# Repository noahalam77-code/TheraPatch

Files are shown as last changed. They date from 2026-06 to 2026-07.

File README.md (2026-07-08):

# TheraPatch

## Repository file structure
- BOM: JCLPCB BOM & regular BOM
- CADfiles: STEP files, STL files, and assembly notes
- PCB: PCB files, Gerber files, schematic images, and PCB images
- Firmware: Code & flashing instructions

## What it is
TheraPatch is a handheld therapeutic device designed to help mitigate the effects of injuries such as bruises, sprains, minor cuts, and more. By using a reverse-polarity system via an H-bridge, TheraPatch can heat the affected area (dilating blood vessels) or cool it (constricting blood vessels), both of which have been shown to help with injury healing at certain temperatures (which TheraPatch can achieve). 

## Motivation
I created TheraPatch with the primary motivation of helping people with common sports/activty related injuries while maintaining an efficient device to do so. Most of the time, when you have a bruise or scrape, you'd rely on disposable ice packs or inefficient heating pads, which are wasteful and time-consuming for long-term use. TheraPatch offers an effective, infinitely reusable solution to this. Instead of freezing water for 3-4 hours or boiling a heatpack everytime you need to reuse it, all you do with TheraPatch is plug and play. It's effective for athletes and normal people.

## Use of TheraPatch
To use the TheraPatch, first ensure your battery/wall adapter is plugged in. Then locate the 4 buttons on the top of the device; these buttons will allow you to set your desired parameters by moving through the menus: mode (hot/cold), set temp, and set time. After your desired settings are set, click the start button to initiate your therapy session, and place the side with the Peltier facing out against the affected area

## How it works
The TheraPatch looks like a simple black-and-white hot-cold block, but its guts are far more advanced. In electronics, generating heat is relatively simple. Electrons bump into each other rapidly in the wire, vibrating and thus creating the heat we feel. This is the easy part; cooling is the real engineering challenge. To cool it, I used a Peltier module, which transfers heat from one side to the other. Now, this needs to be driven by a heatsink and a fan to effectively cool. To achieve heating and cooling on the same side, I used an H bridge. The H-bridge module reverses the polarity in a Peltier module, meaning that when one side is positive and the other is negative, it cools; vice versa. All of this is controlled by a custom 4-layer PCB I designed in KiCad, with an ATmega328P as my microcontroller. The firmware reads a thermistor pressed against the Peltier plate and uses a bang-bang controller to turn the Peltier on/off to reach the desired temperature. This is all run by a rechargeable 12V battery, which charges via USB-C or a 12V wall adapter. These components are combined in a logical order in a CAD-designed box with a hole for all the input plugs and vent fans for air circulation.

Here are images of my project

## CAD with the PCB:

Screenshot 2026-07-04 at 1 53 12 PM

Screenshot 2026-07-04 at 1 53 32 PM

## CAD input ports, fins, and Peliter hole

Screenshot 2026-07-04 at 1 54 11 PM

Screenshot 2026-07-04 at 1 55 22 PM

Screenshot 2026-07-04 at 1 55 41 PM

## Link to Onshape case:

https://cad.onshape.com/documents/d627d659f05dae60588ec801/w/ad74ef98cd2d7a13cb59f9ec/e/f50ed022a94792dc2cfe6130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

# PCB (Signal Layer and ground):

## F.cu (signal traces and ground):

Screenshot 2026-06-03 at 1 51 27 AM

## In1.cu(ground):

Screenshot 2026-06-03 at 1 52 55 AM

## In2.cu (5V & 12V power)

Screenshot 2026-06-03 at 1 53 45 AM

## B.cu (signal traces and ground):

Screenshot 2026-06-03 at 1 54 23 AM

## 3D:

Screenshot 2026-06-03 at 1 55 00 AM

# Schematic (wiring diagram):

## Pic_1:

Screenshot 2026-06-03 at 1 55 57 AM

## Pwr:

Screenshot 2026-06-03 at 1 56 46 AM

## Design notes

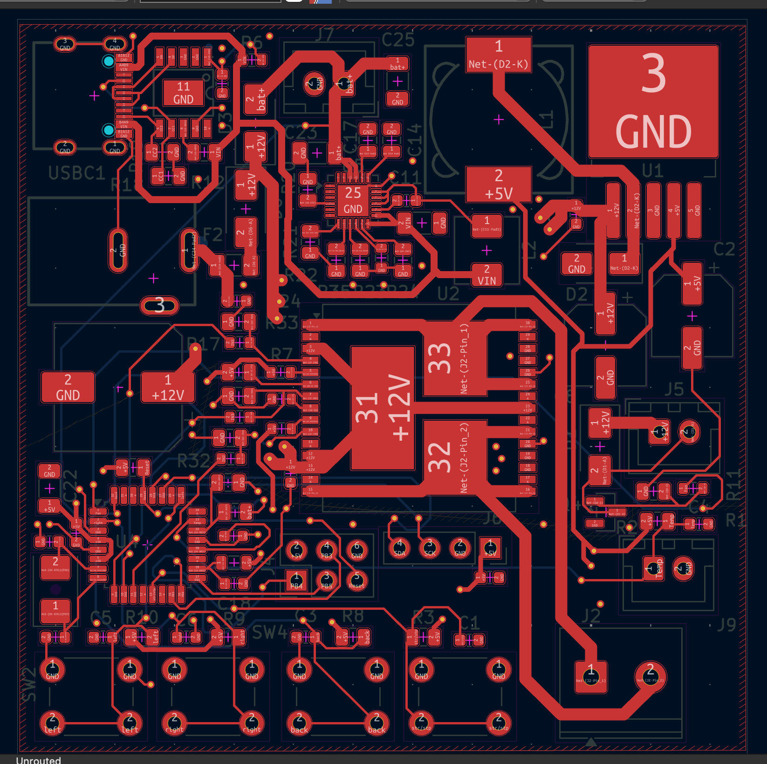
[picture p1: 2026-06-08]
PCB/F.Cu_PCB.png

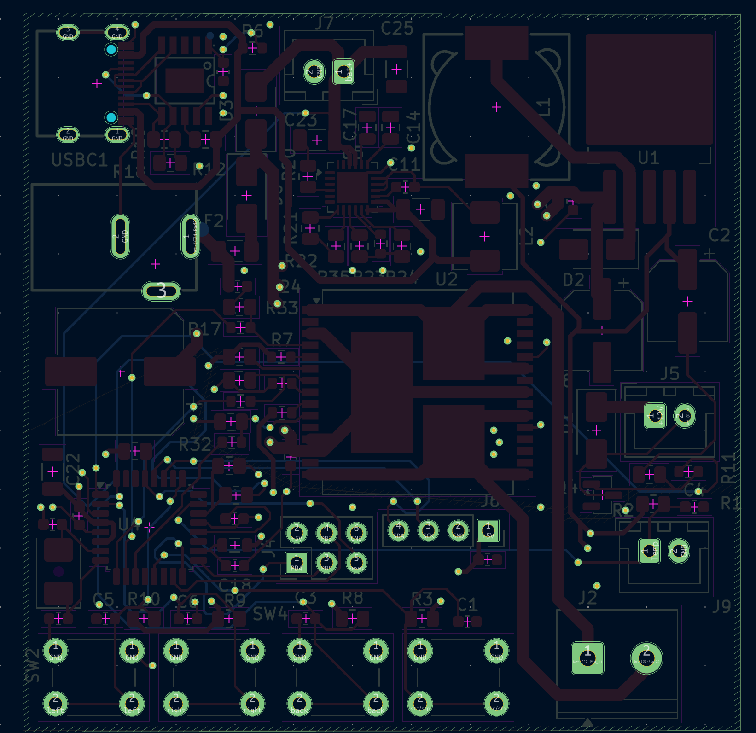
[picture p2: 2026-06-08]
PCB/In1.Cu PCB.png

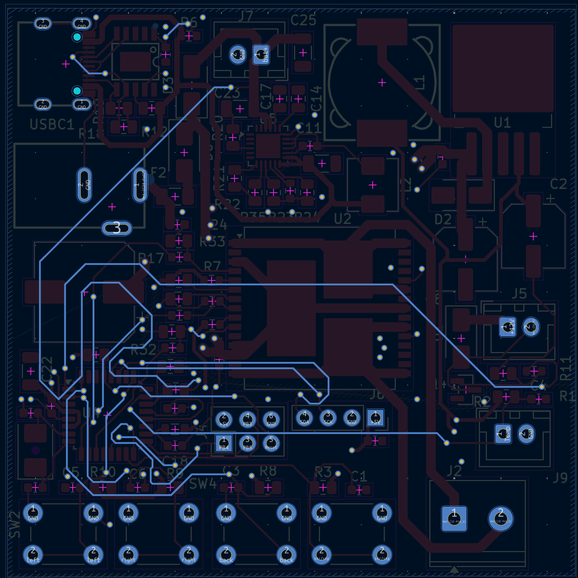
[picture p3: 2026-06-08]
PCB/B.Cu_PCB.png

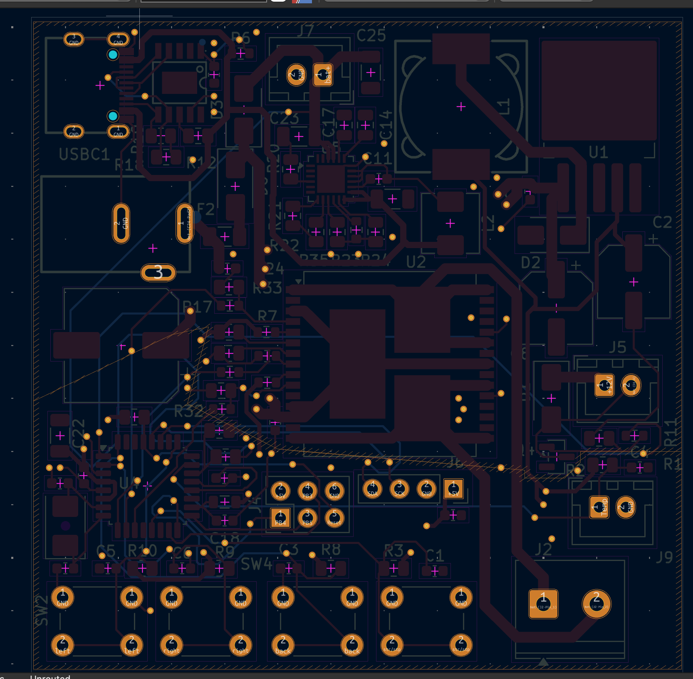
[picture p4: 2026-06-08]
PCB/In2.Cu_PCB.png

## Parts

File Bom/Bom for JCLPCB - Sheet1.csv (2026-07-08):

Comment | Designator | Footprint | LCSC Part Number
USB-C | USBC1 | USBC_U:USB-C_SMD-TYPE-C-31-M-12_1 | C165948
5A Fuse | F2 | Fuse:Fuse_1206_3216Metric | C41367229
Crystal | Y1 | Crystal:Crystal_SMD_5032-2Pin_5.0x3.2mm | C122519
Ferrite bead | FB1 | Inductor_SMD:L_0805_2012Metric | C21519
AO3400A diode | Q4 | Package_TO_SOT_SMD:SOT-23 | C20917
SS54 Diode | D1, D2, D3, D6 | Diode_SMD:D_SMA | C22452
33µH inductor | L1 | inductor_33uh:IND-SMD_L12.3-W12.3 | C9400
120K Resitor | R21, R35 | Resistor_SMD:R_0805_2012Metric | C2907223
90K Resitor | R24 | Resistor_SMD:R_0805_2012Metric | C5123603
68K Resitor | R22 | Resistor_SMD:R_0805_2012Metric | C2907283
51K Resitor | R20 | Resistor_SMD:R_0805_2012Metric | C2933461
47K restior | R27 | Resistor_SMD:R_0805_2012Metric | C2930202
10K Restior | R34, R33, R28, R16, R13, R12, R10, R9, R8, R5, R3, R2, R1 | Resistor_SMD:R_0805_2012Metric | C2907219
5.1K resistor | R18, R19 | Resistor_SMD:R_0805_2012Metric | C27834
3.3K resistor | R7, R14 | Resistor_SMD:R_0603_1608Metric | C2907023
1k resistor | R32, R23, R17, R15, R6, R4 | Resistor_SMD:R_0603_1608Metric | C2907002
100Ω resistor | R11 | Resistor_SMD:R_0603_1608Metric | C105588
220uF capacitor | C2 | Capacitor_SMD:CP_Elec_6.3x7.7 | C22388075
100uF capacitor | C8 | Capacitor_SMD:CP_Elec_6.3x7.7 | C970685
22uF capacitor | C14, C17 | Capacitor_SMD:C_0805_2012Metric | C45783
10uF capacitor | C25, C23, C22,C10 | Capacitor_SMD:C_1206_3216Metric | C9807
1uF capacitor | C7 | Capacitor_SMD:C_0603_1608Metric | C29936
0.1uF capacitor | C24, C19, C18, C15, C13, C12, C11, C9, C6, C5, C4, C3, C1 | Capacitor_SMD:C_0603_1608Metric | C1590
22pF capacitor | C20,C21 | Capacitor_SMD:C_0603_1608Metric | C1653
ST VNH5019ATR-E | U2 | Package_SO:ST_MultiPowerSO-30 | C2653552
LM2596S-5.0 | U1 | Package_TO_SOT_SMD:TO-263-5_TabPin3 | C116713
WCH CH224K | U3 | CH224K:ESSOP-10_L4.9-W3.9-P1.0-LS6.0-TL-EP | C970725
IP2326 | U5 | Package_DFN_QFN:QFN-24-1EP_4x4mm_P0.5mm_EP2.6x2.6mm | C2832094
ATMEGA328P-AU | U4 | Package_QFP:TQFP-32_7x7mm_P0.8mm | C14877

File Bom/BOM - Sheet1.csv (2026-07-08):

Item | Quantity | Unit price | Total price | Descrption | Link
Fan | 1 | 4.81 | 4.81 | Facliate heaitng & cooling | https://www.aliexpress.us/item/3256808462428286.html?curPageLogUid=VweLjIS1lGkI
Peltier | 1 | 3.90$ | $3.90 | Cool and heat | https://www.aliexpress.us/item/3256806863842277.html?src=google&gatewayAdapt=glo2usa
Heatsink | 2 | 4.80$ | $9.79 | Disspate heat | https://www.amazon.com/Awxlumv-Aluminum-60mmx60mmx15mm-Conductive-Amplifier/dp/B0DNLXD4NL
LCD screen | 1 | 0.9900$ | 0.9900$ | Displaying modes | https://www.aliexpress.us/item/3256807264700302.html?curPageLogUid=GNgXD2HWAIP5
Thermistor | 1 | 0.9500$ | 0.9500$ | Temp meauring | https://www.adafruit.com/product/4890
Battery | 1 | 26.99$ | $26.99 | Used as main source of power (for moblity) BMS confirmed | https://liionwholesale.com/products/3s1p-3-7v-3500mah-18650-battery-with-wires-and-connector-lg-mj1-cell-inside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
Wire | 1 | 2.2300$ | 2.23$ | Battery caddy, peliter and fan extesion | https://www.aliexpress.us/item/3256802140205012.html?curPageLogUid=CY0b8Pvel5HR
Wall adapter | 1 | $1.28 | $1.28 | 2nd way of recving power (1st battery) | https://www.aliexpress.us/item/3256806555593510.html?curPageLogUid=H50idJ0yOZub
M2 screw 8mm | 100 | 0.0100$ | $1.35 | screws for battery caddy | https://www.aliexpress.us/item/2251832857570651.html?curPageLogUid=WMcjfyJWRpdQ
M2 screw 14mm | 100 | 0.0100$ | $1.35 | screws for main case | https://www.aliexpress.us/item/2251832857570651.html?curPageLogUid=WMcjfyJWRpdQ
Dupont connectors | 40 | 0.0253$ | 1.01$ | connectors for LCD and ISP proggarmer | https://www.aliexpress.us/item/3256809185840584.html?curPageLogUid=48BAjk6LrSZa
ISP porgrammer | 1 | 1.9100$ | $1.91 | Flashes code onto the ATMega chip | https://www.aliexpress.us/item/3256810618247711.html?curPageLogUid=atD9pSQGrkCO
Buttons | 20 | 0.1095$ | 2.19$ | Switching between menus & 0start/stop | https://www.aliexpress.us/item/3256801638385730.html?curPageLogUid=ypVEuRkxBtEG
Terminal Block | 5 | 0.0864$ | 0.4300$ | For conencting things without JST conenctor | https://www.lcsc.com/product-detail/C394556.html?s_z=n_JILN%2520JL126-50002G01
Barrel Jack | 5 | 0.1462$ | $0.73 | Wall power input | https://www.lcsc.com/product-detail/C720558.html?s_z=n_q_barrel%2520jack%25205A
JST female | 20 | 0.0403$ | 0.81$ | Battery inpt | https://www.lcsc.com/product-detail/C158012.html?s_z=n_q_C158012&globalKeyword=C158012
4 Pin connector for LCD | 10 | 0.0807$ | 0.81$ | LCD input | https://www.lcsc.com/product-detail/C50950.html?s_z=n_q_C50950&globalKeyword=C50950
Arundio flash input | 5 | 0.2238$ | 1.12$ | Pins to flash code | https://www.lcsc.com/product-detail/C50980.html?s_z=n_q_C50980&globalKeyword=C50980
USB-C | 5 | $0.1857 | $0.93 | Charging | https://www.lcsc.com/product-detail/C165948.html?s_z=n_q_C165948&globalKeyword=C165948
5A fuse | 10 | 0.0506$ | $0.51 | PCB | https://www.lcsc.com/product-detail/C41367229.html?s_z=n_q_t_5A%2520smd%2520fuse
16 Mhz cyrstal | 5 | 0.2372$ | $1.19 | PCB | https://www.lcsc.com/product-detail/C122519.html?s_z=n_q_C122519&globalKeyword=C122519
Ferrite Bead | 10 | 0.0262$ | $0.26 | PCB | https://www.lcsc.com/product-detail/C21519.html?s_z=n_q_600%2520ohm%2520ferrite%2520bead%25200805
AO3400A | 5 | 0.0846$ | $0.42 | diode for the fan | https://www.lcsc.com/product-detail/C20917.html?s_z=n_q_C20917&globalKeyword=C20917
SS54 Diode | 10 | 0.0366$ | 0.3700$ | Diode used in buck and input pwr | https://www.lcsc.com/product-detail/C22452.html?s_z=n_q_SS54%2520diode
33uH buck Inductor | 5 | 0.2204$ | 1.10$ | PCB | https://www.lcsc.com/product-detail/C9400.html?s_z=n_q_t_33uH%2520SMD%2520ind
2.2uH boost Inductor | 5 | 0.1161$ | $0.58 | PCB | https://www.lcsc.com/product-detail/C7461347.html?s_z=n_q_CXP0530-2R2M-AG
120K resistor | 100 | $0.0022 | $0.22 | PCB | https://www.lcsc.com/product-detail/C2907223.html?s_z=n_q_C2907223&globalKeyword=C2907223
90K resitor | 10 | $0.0654 | $0.65 | PCB | https://www.lcsc.com/product-detail/C5123603.html?s_z=n_q_C5123603&globalKeyword=C5123603
68K resistor | 100 | $0.0021 | $0.21 | PCB | https://www.lcsc.com/product-detail/C2907283.html?s_z=n_q_C2907283&globalKeyword=C2907283
51k resistor | 100 | $0.0021 | $0.21 | PCB | https://www.lcsc.com/product-detail/C2933461.html?s_z=n_q_C2933461&globalKeyword=C2933461
47K resistor | 100 | $0.0021 | $0.21 | PCB | https://www.lcsc.com/product-detail/C2930202.html?s_z=n_q_C2930202&globalKeyword=C2930202
10K resistor | 100 | $0.0020 | $0.20 | PCB | https://www.lcsc.com/product-detail/C2907219.html?s_z=n_q_C2907219&globalKeyword=C2907219
5.1K resistor | 100 | $0.00 | $0.27 | PCB | https://www.lcsc.com/product-detail/C27834.html?s_z=n_q_C27834&globalKeyword=C27834
3.3K resistor | 100 | $0.0020 | $0.20 | PCB | https://www.lcsc.com/product-detail/C2907023.html?s_z=n_q_t_3.3K%2520resistor
1k resistor | 100 | $0.0076 | $0.76 | PCB | https://www.lcsc.com/product-detail/C2907002.html?s_z=n_q_t_0603%25201k%25CE%25A9%2520
100Ω resistor | 100 | $0.0014 | $0.14 | PCB | https://www.lcsc.com/product-detail/C105588.html?s_z=n_q_t_100%25CE%25A9%2520resistor
470uF capacitor | 5 | $0.0875 | $0.44 | PCB | https://www.lcsc.com/product-detail/C976030.html
220uF capacitor | 10 | $0.0276 | $0.28 | PCB | https://www.lcsc.com/product-detail/C22388075.html
100uF capacitor | 20 | $0.0372 | $0.74 | PCB | https://www.lcsc.com/product-detail/C970685.html?s_z=n_q_C970685&globalKeyword=C970685
22uF capacitor | 20 | $0.0349 | $0.70 | PCB | https://www.lcsc.com/product-detail/C45783.html?s_z=n_q_C45783&globalKeyword=C45783
10uF capacitor | 10 | $0.0394 | $0.39 | PCB | https://www.lcsc.com/product-detail/C9807.html
1uF capacitor | 50 | $0.0069 | $0.35 | PCB | https://www.lcsc.com/product-detail/C29936.html
0.1uF capacitor | 100 | $0.004 | $0.40 | PCB | https://www.lcsc.com/product-detail/C1590.html
22pF capacitor | 100 | $0.0041 | $0.41 | PCB | https://www.lcsc.com/product-detail/C1653.html?s_z=n_q_C1653&globalKeyword=C1653
ST VNH5019ATR-E | 1 | 9.36$ | 9.36$ | H-bridge to switch polairty | https://www.lcsc.com/product-detail/C2653552.html?s_z=n_VNH5019A-E
LM2596S-5.0 | 1 | 1.42$ | 1.37$ | Buck convetor for non 12V parts | https://www.lcsc.com/product-detail/C116713.html?s_z=n_LM2596S-5
WCH CH224K | 1 | $0.61 | $0.61 | Power negogatior, Requests 9V | https://www.lcsc.com/product-detail/C970725.html?s_z=n_q_CH224K
IP2326 | 1 | $0.62 | $0.62 | Boost converter for charging 9V to 12.6V | https://www.lcsc.com/product-detail/C2832094.html?s_z=n_q_IP2326
ATMEGA328P-AU | 1 | $2.65 | $2.65 | Microcontroller | https://www.lcsc.com/product-detail/C14877.html?s_z=n_q_ATmega328P-A

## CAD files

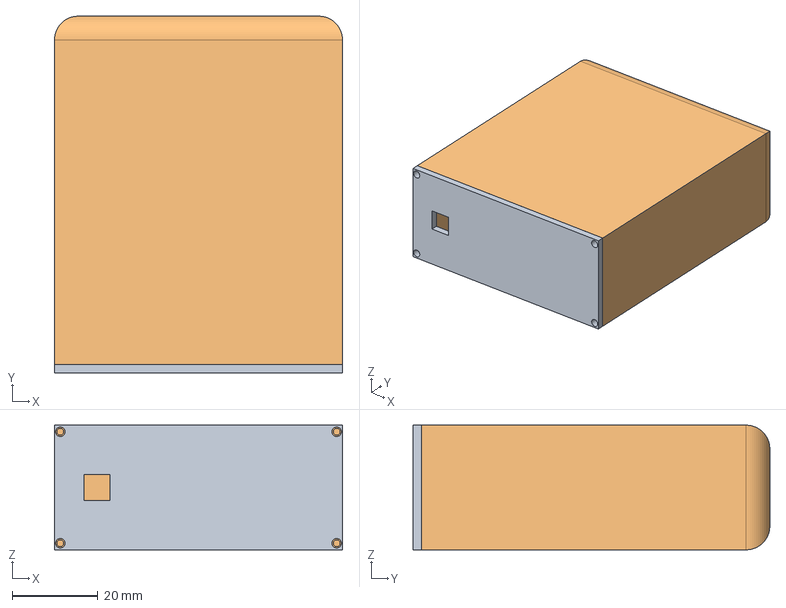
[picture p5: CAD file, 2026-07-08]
CADfiles/Battery Assembly (1).step
67.0 x 83.0 x 29.0 mm

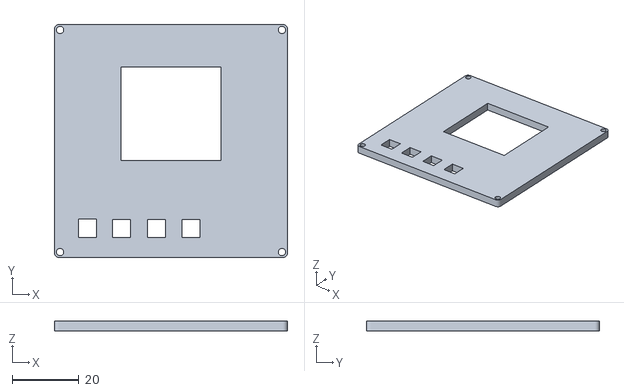
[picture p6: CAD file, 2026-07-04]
CADfiles/Lid.stl
70.0 x 70.0 x 3.00

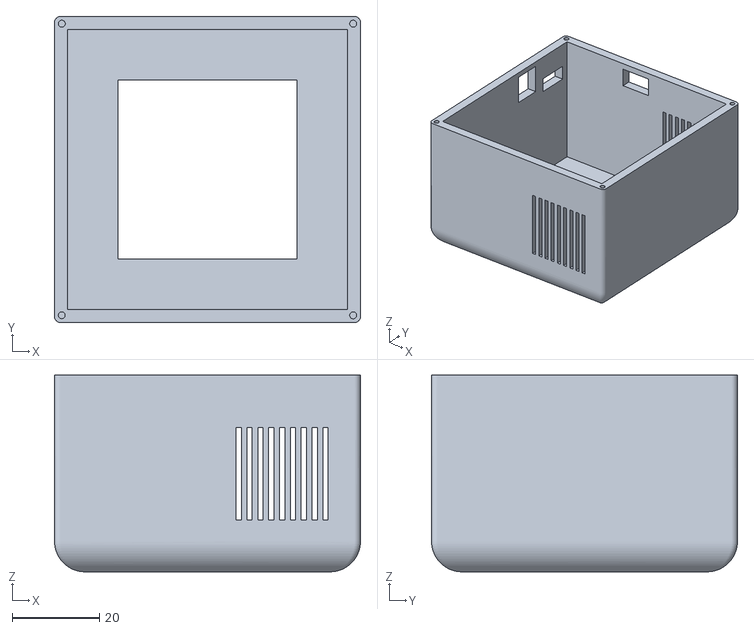
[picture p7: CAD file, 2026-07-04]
CADfiles/case.stl
70.0 x 70.0 x 45.0

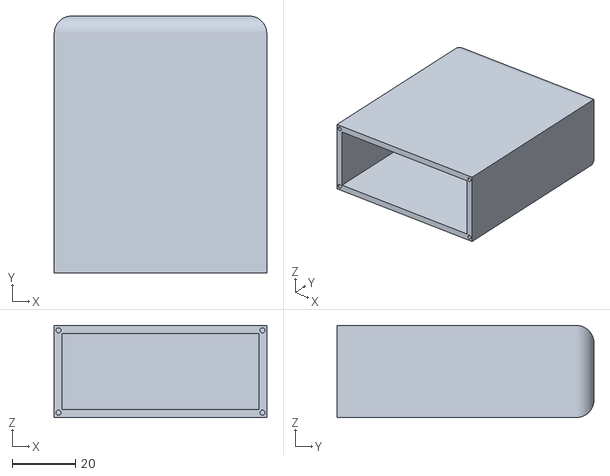
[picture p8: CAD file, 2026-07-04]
CADfiles/Battery.stl
67.0 x 81.0 x 29.0

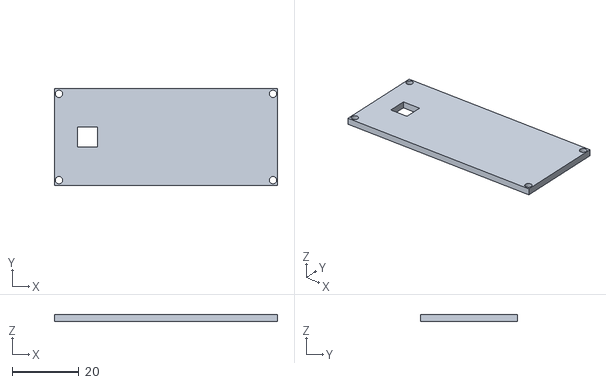
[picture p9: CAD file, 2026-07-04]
CADfiles/Battery top.stl
67.0 x 29.0 x 2.00

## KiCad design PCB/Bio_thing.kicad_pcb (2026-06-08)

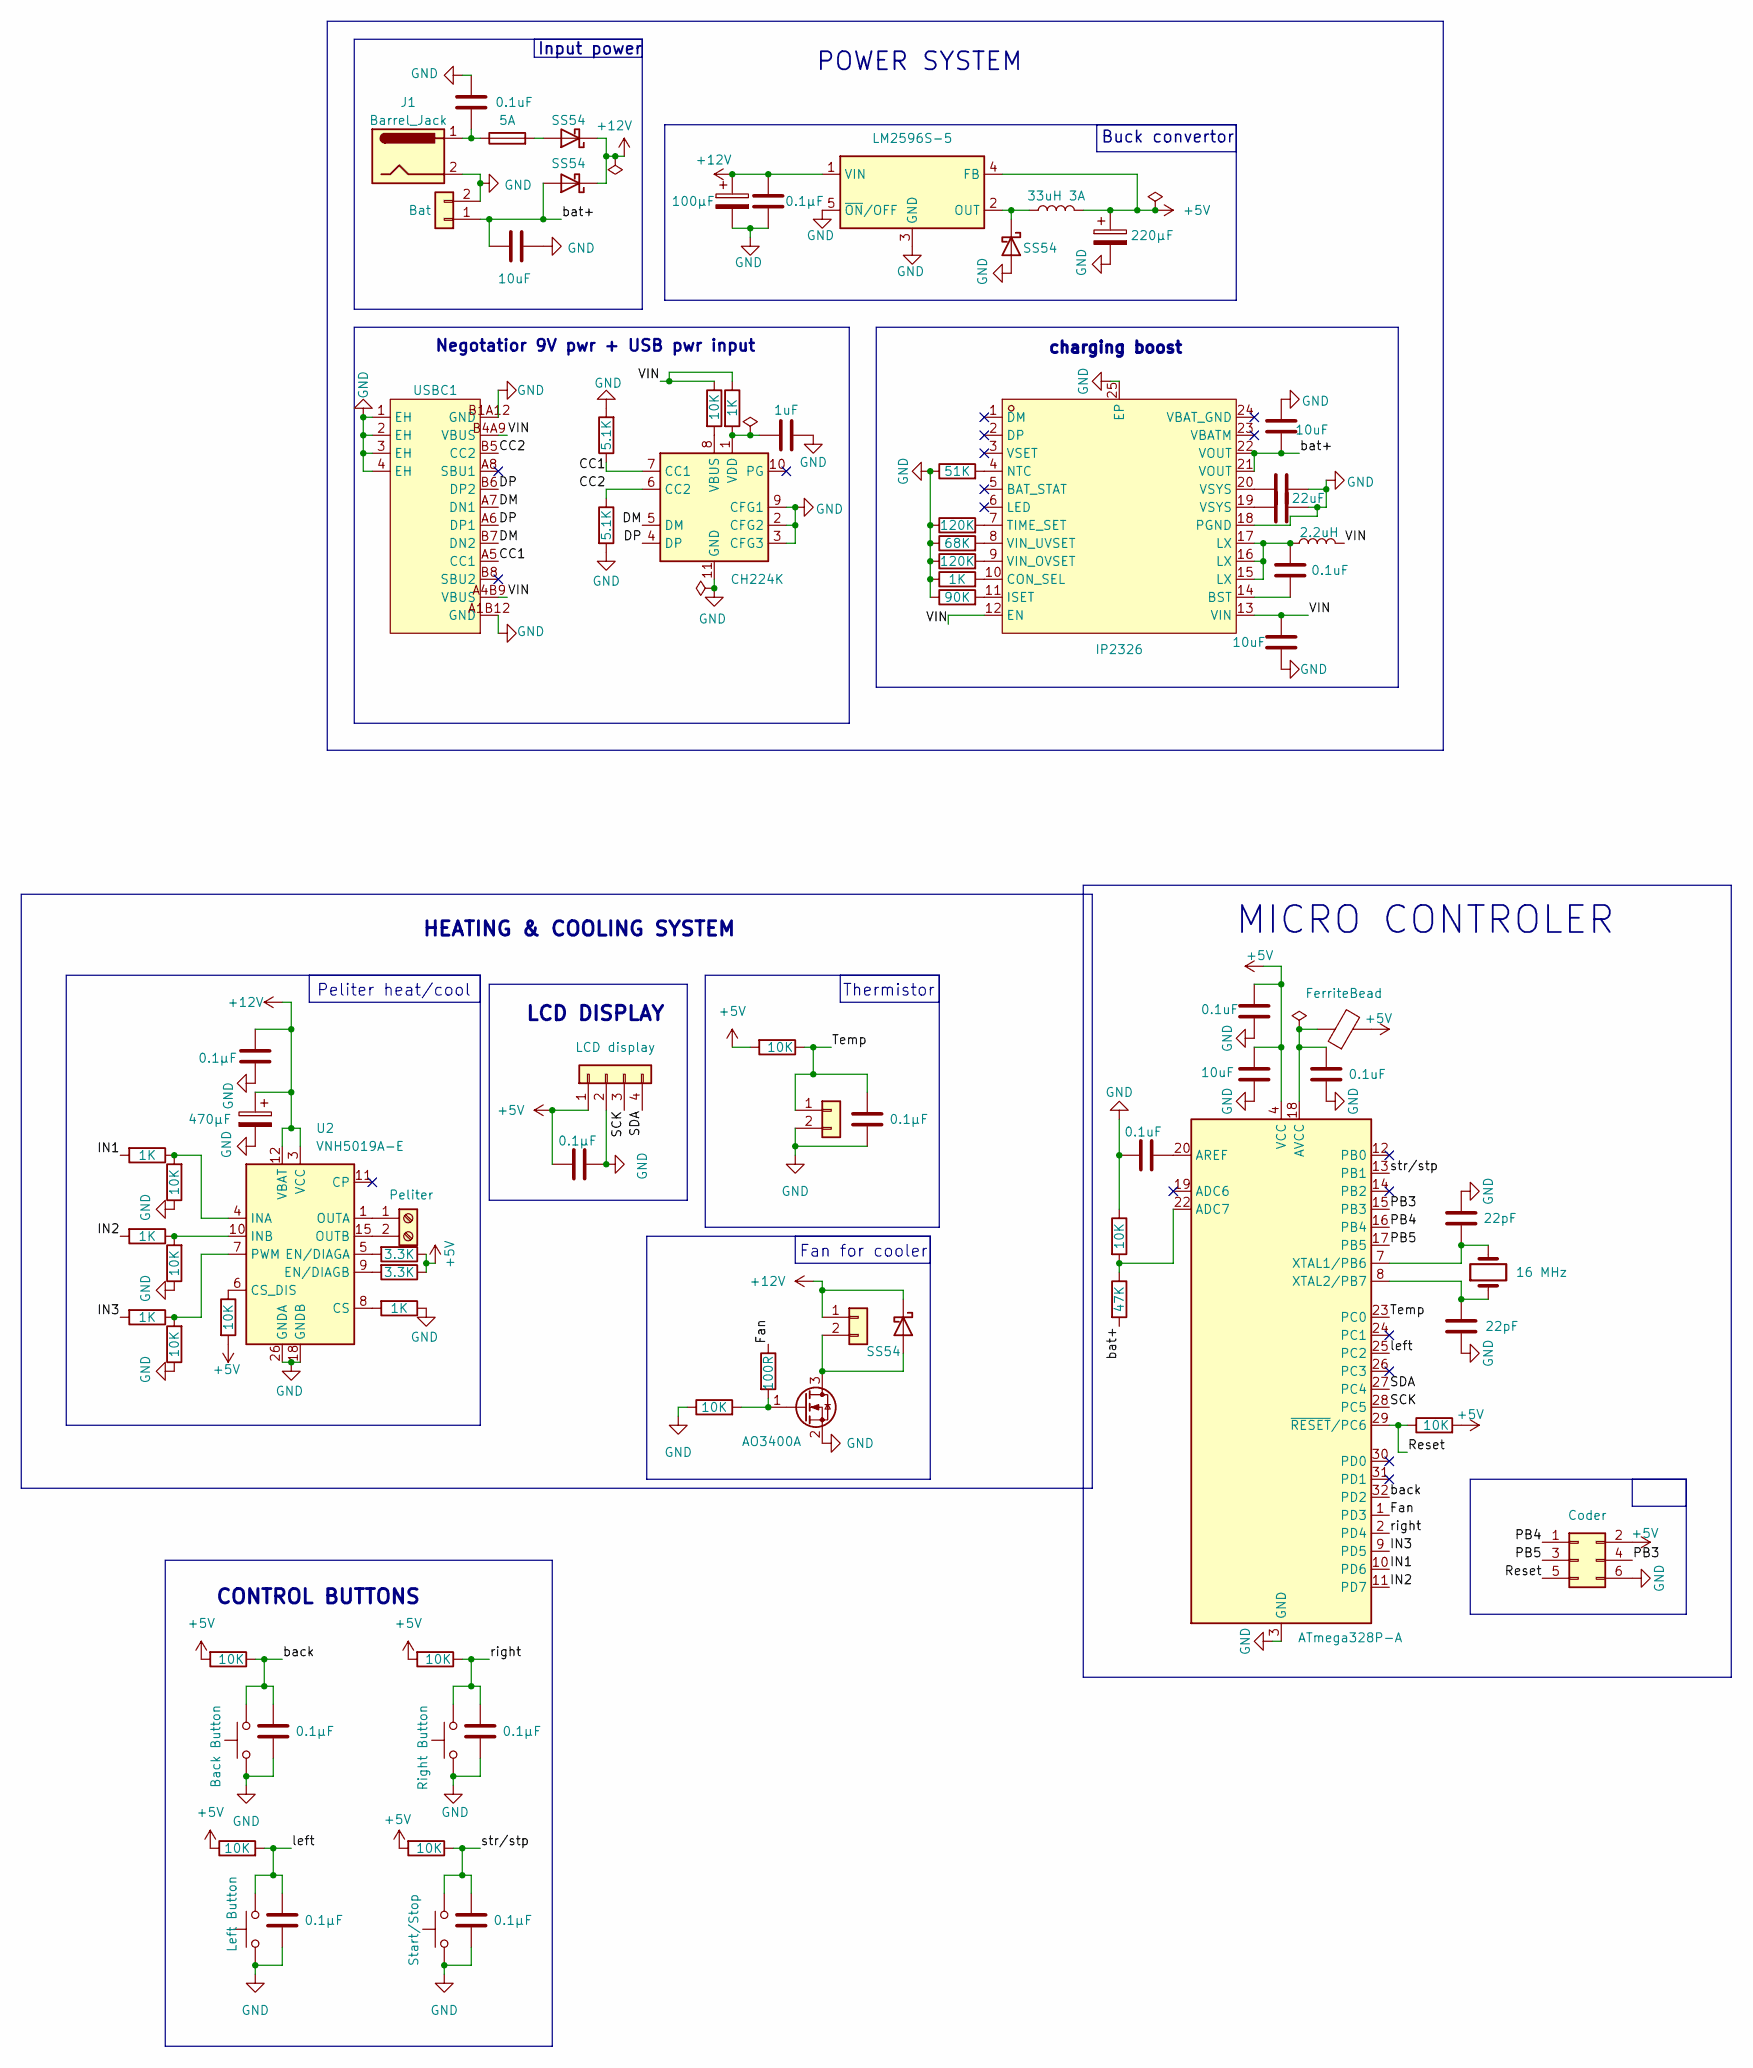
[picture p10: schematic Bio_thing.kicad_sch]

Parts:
C1, C3, C4, C5, C6, C9, C12, C15: 0.1µF; C_0603_1608Metric
C2: 220µF; CP_Elec_6.3x7.7
C7: 1uF; C_0603_1608Metric
C8: 100µF; CP_Elec_6.3x7.7
C10, C22, C23, C25: 10uF; C_1206_3216Metric
C11, C13, C18, C19, C24: 0.1uF; C_0603_1608Metric
C14, C17: 22uF; C_0805_2012Metric
C16: 470µF; CP_Elec_10x10.5
C20, C21: 22pF; C_0603_1608Metric
D1, D2, D3, D6: SS54; D_SMA
F2: 5A; Fuse_1206_3216Metric
FB1: FerriteBead; L_0805_2012Metric
J1: Barrel_Jack; Barrel_JJack
J2: Peliter; TerminalBlock_Phoenix_PT-1,5-2-5.0-H_1x02_P5.00mm_Horizontal
J4: Coder; PinHeader_2x03_P2.54mm_Vertical
J5: fan; JST_XH_B2B-XH-A_1x02_P2.50mm_Vertical
J6: LCD display; PinSocket_1x04_P2.54mm_Vertical
J7: Bat; JST_XH_B2B-XH-A_1x02_P2.50mm_Vertical
J9: themrisotorr; JST_XH_B2B-XH-A_1x02_P2.50mm_Vertical
L1: 33uH 3A; IND-SMD_L12.3-W12.3
L2: 2.2uH; L_Sunlord_MWSA0503S
Q4: AO3400A; SOT-23
R1, R2, R3, R5, R8, R9, R10, R12, R13, R16, R28, R33, R34: 10K; R_0805_2012Metric
R4, R6, R15, R17, R23, R32: 1K; R_0603_1608Metric
R7, R14: 3.3K; R_0603_1608Metric
R11: 100R; R_0603_1608Metric
R18, R19: 5.1K; R_0805_2012Metric
R20: 51K; R_0805_2012Metric
R21, R35: 120K; R_0805_2012Metric
R22: 68K; R_0805_2012Metric
R24: 90K; R_0805_2012Metric
R27: 47K; R_0805_2012Metric
SW2: Left Button; SW_PUSH_6mm_H4.3mm
SW3: Start/Stop; SW_PUSH_6mm_H4.3mm
SW4: Back Button; SW_PUSH_6mm_H4.3mm
SW5: Right Button; SW_PUSH_6mm_H4.3mm
U1: LM2596S-5; TO-263-5_TabPin3
U2: VNH5019A-E; ST_MultiPowerSO-30
U3: CH224K; ESSOP-10_L4.9-W3.9-P1.0-LS6.0-TL-EP
U4: ATmega328P-A; TQFP-32_7x7mm_P0.8mm
U5: IP2326; QFN-24-1EP_4x4mm_P0.5mm_EP2.6x2.6mm; MPN IP2326; LCSC Part C2832094
USBC1: TYPE-C-31-M-12; USB-C_SMD-TYPE-C-31-M-12_1; MPN TYPE-C-31-M-12; LCSC Part C165948
Y1: 16 MHz; Crystal_SMD_5032-2Pin_5.0x3.2mm

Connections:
+5V: C2.1, C12.1, C13.1, C22.1, FB1.2, J4.2, J6.1, L1.2, R2.2, R3.2, R5.2, R7.1, R8.2, R9.2, R10.1, R13.2, R14.1, U1.4 (FB), U4.4 (VCC), U4.6 (VCC)
+12V: C8.1, C9.1, C15.1, C16.1, D1.1 (K), D3.1 (K), D6.1 (K), J5.1, U1.1 (VIN), U2.3 (VCC), U2.12 (VBAT), U2.13 (VCC), U2.23 (VCC), U2.31 (VCC)
/CC1: R18.1, U3.7 (CC1), USBC1.A5 (CC1)
/CC2: R19.1, U3.6 (CC2), USBC1.B5 (CC2)
/DM: U3.5 (DM), USBC1.A7 (DN1), USBC1.B7 (DN2)
/DP: U3.4 (DP), USBC1.A6 (DP1), USBC1.B6 (DP2)
/Fan: R11.1, U4.1 (PD3)
/IN1: R17.2, U4.10 (PD6)
/IN2: R32.2, U4.11 (PD7)
/IN3: R15.2, U4.9 (PD5)
/PB3: J4.4, U4.15 (PB3)
/PB4: J4.1, U4.16 (PB4)
/PB5: J4.3, U4.17 (PB5)
/Reset: J4.5, R13.1, U4.29 (~RESET/PC6)
/SCK: J6.3, U4.28 (PC5)
/SDA: J6.4, U4.27 (PC4)
/Temp: C4.1, J9.1, R2.1, U4.23 (PC0)
/VIN: C10.2, L2.2, R6.1, R12.1, U5.12 (EN), U5.13 (VIN), USBC1.A4B9 (VBUS), USBC1.B4A9 (VBUS)
/back: C3.1, R8.1, SW4.2, U4.32 (PD2)
/bat+: C23.1, C25.1, D3.2 (A), J7.1, R27.2, U5.21 (VOUT), U5.22 (VOUT)
/left: C5.1, R10.2, SW2.2, U4.25 (PC2)
/right: C6.1, R9.1, SW5.2, U4.2 (PD4)
/str/stp: C1.1, R3.1, SW3.2, U4.13 (PB1)
GND: C1.2, C2.2, C3.2, C4.2, C5.2, C6.2, C7.2, C8.2, C9.2, C10.1, C12.2, C13.2, C14.2, C15.2, C16.2, C17.2, C18.2, C19.1, C20.2, C21.1, C22.2, C23.2, C24.1, C25.2, D2.2 (A), J1.2, J4.6, J6.2, J7.2, J9.2, Q4.2 (S), R1.1, R4.1, R16.1, R18.2, R19.2, R20.1, R21.1, R22.1, R23.1, R24.1, R28.1, R33.1, R34.1, R35.1, SW2.1, SW3.1, SW4.1, SW5.1, U1.3 (GND), U1.5 (~ON/OFF), U2.18 (GNDB), U2.19 (GNDB), U2.20 (GNDB), U2.26 (GNDA), U2.27 (GNDA), U2.28 (GNDA), U3.2 (CFG2), U3.3 (CFG3), U3.9 (CFG1), U3.11 (GND), U4.3 (GND), U4.5 (GND), U4.21 (GND), U5.18 (PGND), U5.25 (EP), USBC1.1 (EH), USBC1.2 (EH), USBC1.3 (EH), USBC1.4 (EH), USBC1.A1B12 (GND), USBC1.B1A12 (GND)
unnamed: C11.1, L2.1, U5.15 (LX), U5.16 (LX), U5.17 (LX)
unnamed: C14.1, U5.19 (VSYS)
unnamed: C17.1, U5.20 (VSYS)
unnamed: C24.2, F2.1, J1.1
unnamed: D1.2 (A), J5.2, Q4.3 (D)
unnamed: D2.1 (K), L1.1, U1.2 (OUT)
unnamed: D6.2 (A), F2.2
unnamed: J2.1, U2.1 (OUTA), U2.25 (OUTA), U2.30 (OUTA), U2.33 (OUTA)
unnamed: J2.2, U2.15 (OUTB), U2.16 (OUTB), U2.21 (OUTB), U2.32 (OUTB)
unnamed: Q4.1 (G), R1.2, R11.2
unnamed: R4.2, U2.8 (CS)
unnamed: R5.1, U2.6 (CS_DIS)
unnamed: R7.2, U2.5 (EN/DIAGA)
unnamed: R14.2, U2.9 (EN/DIAGB)
unnamed: R17.1, R33.2, U2.4 (INA)
unnamed: R32.1, R34.2, U2.10 (INB)
unnamed: R15.1, R16.2, U2.7 (PWM)
unnamed: R12.2, U3.8 (VBUS)
unnamed: C7.1, R6.2, U3.1 (VDD)
unnamed: R27.1, R28.2, U4.22 (ADC7)
unnamed: C19.2, U4.20 (AREF)
unnamed: C18.1, FB1.1, U4.18 (AVCC)
unnamed: C21.2, U4.7 (XTAL1/PB6), Y1.2
unnamed: C20.1, U4.8 (XTAL2/PB7), Y1.1
unnamed: C11.2, U5.14 (BST)
unnamed: R23.2, U5.10 (CON_SEL)
unnamed: R24.2, U5.11 (ISET)
unnamed: R20.2, U5.4 (NTC)
unnamed: R21.2, U5.7 (TIME_SET)
unnamed: R35.2, U5.9 (VIN_OVSET)
unnamed: R22.2, U5.8 (VIN_UVSET)

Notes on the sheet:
Thermistor
MICRO CONTROLER
Negotatior 9V pwr + USB pwr input
Peliter heat/cool
charging boost
POWER SYSTEM
HEATING & COOLING SYSTEM
LCD DISPLAY
Buck convertor
Input power
Fan for cooler
CONTROL BUTTONS

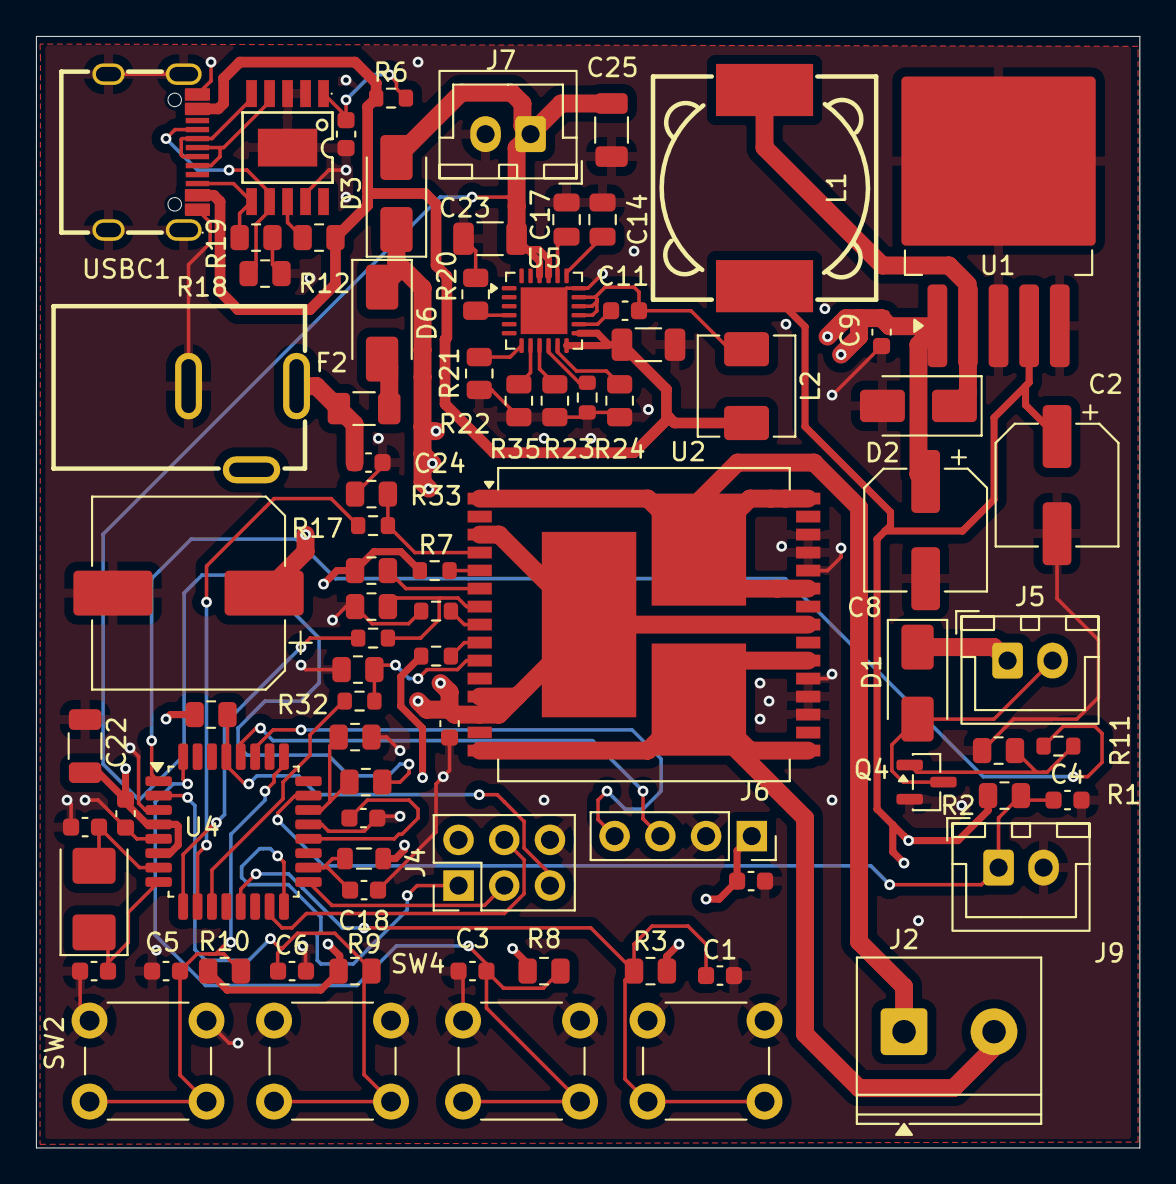
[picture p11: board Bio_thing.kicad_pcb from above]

Board: 4 copper layers, 61.3 x 61.7 mm, 82 parts (0 on the bottom side), 55 nets.

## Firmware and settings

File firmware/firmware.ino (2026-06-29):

//TheraPatch project COOODDEEEEEEEEEEE final
//
//
//
#include <U8g2lib.h>   
#include <Wire.h>     
U8G2_SSD1306_128X64_NONAME_F_HW_I2C u8g2(U8G2_R0, U8X8_PIN_NONE);
//buttons
#define BTN_LEFT A2   
#define BTN_RIGHT 4    
#define BTN_BACK 2   
#define BTN_START 9    
#define PIN_TEMP A0  
#define PIN_BATT A7  
#define PIN_FAN 3    
#define PIN_INA 6  
#define PIN_INB 7    
#define PIN_PWM 5   
// themisotr calabration
#define BETA_VLU 3950.0
#define T_R 10000.0    
#define KELVIN 298.15     
#define TEN_R 10000.0  

//Battery Dispplay
#define VOLT_SCL 5.7       
#define BATT_FULL 12.6       
#define BATT_EMPTY 9.0     
// safety cuttof
#define WIGGLE 1    
#define COLD_CUTOFF 30  
#define HOT_CUTOFF 113  
#define PWM_FULL 255  
//ranges
#define COLD_MIN 35
#define COLD_MAX 60
#define HOT_MIN 93
#define HOT_MAX 108
#define TIME_MIN 5
#define TIME_MAX 30
//screens
#define MODE 0
#define TEMP 1
#define TIME 2
#define RUN 3
#define DONE 4
#define ERROR 5

//Memory
int screen = MODE;  
int mode = 0;    
int target = 60;   
int minutes = 15;   

unsigned long lastTick = 0;  
unsigned long lastCtrl = 0;  
int secondsLeft = 0;         
int curTemp = 0;             
int batt = 0;           

//PELITER AND FAN CONTROL
//
//
void peltierOff() {
  analogWrite(PIN_PWM, 0);    
  digitalWrite(PIN_INA, LOW);
  digitalWrite(PIN_INB, LOW);
  digitalWrite(PIN_FAN, LOW);
}

//skin side cold
void peltierCool() {
  digitalWrite(PIN_INA, HIGH);
  digitalWrite(PIN_INB, LOW);
  analogWrite(PIN_PWM, PWM_FULL);
  digitalWrite(PIN_FAN, HIGH); 
}

// skin side hot
void peltierHeat() {
  digitalWrite(PIN_INA, LOW);
  digitalWrite(PIN_INB, HIGH);
  analogWrite(PIN_PWM, PWM_FULL);
  digitalWrite(PIN_FAN, HIGH);
}

//themsitor reading
int readTempF() {
  int raw = analogRead(PIN_TEMP);
  if (raw <= 0 || raw >= 1023) {
    return -100;  
  }
  
  float ratio = 1023.0 / raw;       
  float r = TEN_R  * (ratio - 1.0); 
  float a = 1.0 / KELVIN;                   
  float b = (1.0 / BETA_VLU) * log(r / T_R);
  float tK = 1.0 / (a + b);               
  float tC = tK - 273.15;
  float tF = tC * 9.0 / 5.0 + 32.0;
  return (int)tF;
}

// battery reading
int readBattPct() {
  int raw = analogRead(PIN_BATT);
  float v = (raw / 1023.0) * 5.0 * VOLT_SCL;   
  int pct = (int)(((v - BATT_EMPTY) / (BATT_FULL - BATT_EMPTY)) * 100.0);
  if (pct < 0)   pct = 0;     
  if (pct > 100) pct = 100;     
  return pct;
}

//BUTTONS
//
//
int lLeft = HIGH, lRight = HIGH, lBack = HIGH, lStart = HIGH;
bool press(int pin, int &last) {
  int now = digitalRead(pin);
  bool justPressed = (now == LOW && last == HIGH);
  last = now;
  return justPressed;
}

void startRun() {
  secondsLeft = minutes * 60;
  lastTick = millis();
  lastCtrl = 0;
  screen = RUN;
}
void stopRun() {
  peltierOff();
  screen = MODE;
}

void onLeft() {
  if (screen == MODE) 
    mode = 0;
  else if (screen == TEMP) target = (mode == 0) ? max(COLD_MIN, target - 1) : max(HOT_MIN, target - 1);
  else if (screen == TIME) minutes = max(TIME_MIN, minutes - 1);
}
void onRight() {
  if (screen == MODE) 
    mode = 1;
  else if (screen == TEMP) target = (mode == 0) ? min(COLD_MAX, target + 1) : min(HOT_MAX, target + 1);
  else if (screen == TIME) minutes = min(TIME_MAX, minutes + 1);
}
void onStart() {
  if (screen == MODE) 
    { target = (mode == 0) ? 60 : 104; screen = TEMP; }
  else if (screen == TEMP) screen = TIME;
  else if (screen == TIME) startRun();
  else if (screen == RUN)  stopRun();
  else                     screen = MODE;
}
void onBack() {
  if (screen == TEMP) 
    screen = MODE;
  else if (screen == TIME) screen = TEMP;
  else if (screen == RUN)  stopRun();
  else if (screen == DONE || screen == ERROR) screen = MODE;
}


//LCD SCREEN
//
//
void centerStr(int y, const char* s) {
  int w = u8g2.getStrWidth(s);
  u8g2.drawStr((128 - w) / 2, y, s);
}
void drawSetup(const char* title, const char* big, const char* point) {
  u8g2.setFont(u8g2_font_6x10_tr);
  centerStr(12, title);
  u8g2.setFont(u8g2_font_ncenB14_tr);
  centerStr(40, big);
  u8g2.setFont(u8g2_font_5x7_tr);
  centerStr(60, point);
}                        

void drawRun() {
  char buf[16];

  u8g2.setFont(u8g2_font_5x7_tr);

  // battery bar
  snprintf(buf, sizeof(buf), "%d%%", batt);
  u8g2.drawStr(0, 8, buf);

  // current temp 
  snprintf(buf, sizeof(buf), "%dF", curTemp);
  int w = u8g2.getStrWidth(buf);
  u8g2.drawStr((128 - w) / 2, 8, buf);
  // mode on the right
  const char* m = (mode == 0) ? "COOL" : "HEAT";
  w = u8g2.getStrWidth(m);
  u8g2.drawStr(128 - w, 8, m);
  // staus bar speration
  u8g2.drawHLine(0, 12, 128);
//main aereia
  // target temp
  u8g2.setFont(u8g2_font_ncenB10_tr);
  snprintf(buf, sizeof(buf), "Target %dF", target);
  centerStr(34, buf);
  //  timer
  u8g2.setFont(u8g2_font_ncenB14_tr);
  snprintf(buf, sizeof(buf), "%02d:%02d", secondsLeft / 60, secondsLeft % 60);
  centerStr(58, buf);
}
// scrren dispaly
void draw() {
  char buf[16];
  u8g2.clearBuffer();

  if (screen == MODE) {
    drawSetup("SET MODE", (mode == 0) ? "COLD" : "HOT", "< COLD    HOT >");
  }
  else if (screen == TEMP) {
    snprintf(buf, sizeof(buf), "%d F", target);
    drawSetup("SET TEMP", buf, "<  -        +  >");
  }
  else if (screen == TIME) {
    snprintf(buf, sizeof(buf), "%d min", minutes);
    drawSetup("SET TIME", buf, "<  -        +  >");
  }
  else if (screen == RUN) {
    drawRun();
  }
  else if (screen == DONE) {
    u8g2.setFont(u8g2_font_ncenB14_tr);
    centerStr(30, "DONE");
    u8g2.setFont(u8g2_font_6x10_tr);
    centerStr(50, "press any key");
  }
  else if (screen == ERROR) {
    u8g2.setFont(u8g2_font_ncenB14_tr);
    centerStr(30, "ERROR");
    u8g2.setFont(u8g2_font_6x10_tr);
    centerStr(50, "check sensor");
  }
  u8g2.sendBuffer();
}
//SAFTEY AND BANG BANG
//
//
void controlTick() {
  int t = readTempF();

  // Saftery
  if (t == -100) { peltierOff(); screen = ERROR; return; }
  curTemp = t;
  if (mode == 0 && t <= COLD_CUTOFF) { peltierOff(); screen = ERROR; return; }
  if (mode == 1 && t >= HOT_CUTOFF)  { peltierOff(); screen = ERROR; return; }

 // bang bang
  if (mode == 0) {                       
    int tooWarm   = target + WIGGLE;     
    int coldEnough = target - WIGGLE;   

    if (t > tooWarm) {
      peltierCool();                   
    }
    else if (t < coldEnough) {
      peltierOff();                 
    }
  }
  else {                                 
    int tooCool   = target - WIGGLE;     
    int hotEnough = target + WIGGLE;   

    if (t < tooCool) {
      peltierHeat();                 
    }
    else if (t > hotEnough) {
      peltierOff();                     
    }
  }
}
//SETUP BOARD WHEN PLUGED
//
//
void setup() {
  pinMode(PIN_INA, OUTPUT);
  pinMode(PIN_INB, OUTPUT);
  pinMode(PIN_PWM, OUTPUT);
  pinMode(PIN_FAN, OUTPUT);
  peltierOff();


  pinMode(BTN_LEFT,  INPUT);
  pinMode(BTN_RIGHT, INPUT);
  pinMode(BTN_BACK,  INPUT);
  pinMode(BTN_START, INPUT);

  u8g2.begin();  
}

//Big loop
//
//
void loop() {
  if (press(BTN_LEFT,  lLeft))  onLeft();
  if (press(BTN_RIGHT, lRight)) onRight();
  if (press(BTN_START, lStart)) onStart();
  if (press(BTN_BACK,  lBack))  onBack();

  batt = readBattPct();  
  if (screen == RUN) {
    if (millis() - lastCtrl >= 500) { lastCtrl = millis(); controlTick(); }
    if (millis() - lastTick >= 1000) {
      lastTick += 1000;
      if (secondsLeft > 0) secondsLeft--;
      if (secondsLeft == 0) { peltierOff(); screen = DONE; } 
    }
  }

  draw();        
  delay(20);   
}

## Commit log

2026-06-01 Create PCB
2026-06-03 Create Schematic
2026-06-08 Rename In1.Cu PCB.png to PCB/In1.Cu PCB.png
2026-07-04 Update BOM for JCLPCB
2026-07-04 Update BOM file structure
2026-07-04 Create CAD files
2026-07-04 Create CAD files1
2026-07-04 Update CAD files
2026-07-04 Rename TheraPatch Assembly.step to CADfiles/TheraPatch step
2026-07-04 Rename Battery Assembly.step to Battery step
2026-07-04 Fix Onshape case link in README
    Updated the Onshape case link in the README.
2026-07-04 Revise README with new CAD images and descriptions
    Updated images and descriptions in the README to reflect CAD designs and input ports.
2026-07-04 Add assembly notes for therapatch device
    Added assembly notes for the therapatch device detailing the build components, dimensions, and design considerations.
2026-07-06 Add firmware flashing instructions
    Added detailed instructions for flashing firmware using Arduino IDE and USBasp programmer.
2026-07-06 Revise README.md for TheraPatch device details
    Updated the description of TheraPatch for clarity and added usage instructions. Improved language for better readability and corrected minor typos.
2026-07-08 Clarify PCB section description in README
    Updated the description of the PCB section in the README.
2026-07-08 Rename BOM - Sheet1 (9).csv to BOM - Sheet1.csv
    [BOM - Sheet1.csv]
2026-07-08 Rename BOM file for JCLPCB
    [Bom for JCLPCB - Sheet1.csv]
